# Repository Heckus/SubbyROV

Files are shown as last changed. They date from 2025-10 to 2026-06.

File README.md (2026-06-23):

<div align="center">
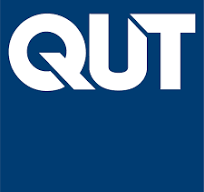
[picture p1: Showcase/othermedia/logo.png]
QUT Logo
  

  
  
  
</div>

# SubbyROV: A Small-Scale Underwater ROV

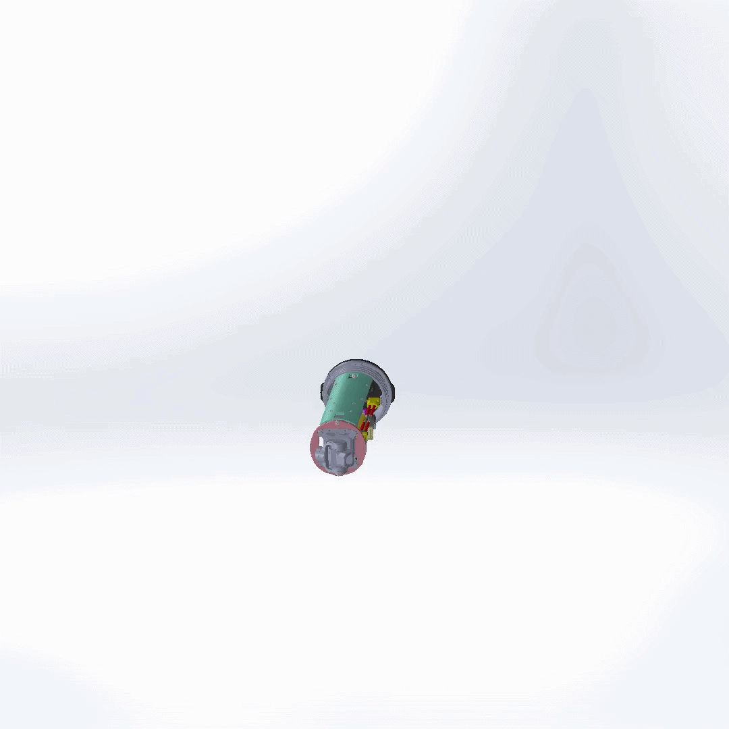
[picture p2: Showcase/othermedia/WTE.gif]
|  |  |
| :---: | :---: |
| *Final SolidWorks Render* | *WTE Design Render* |
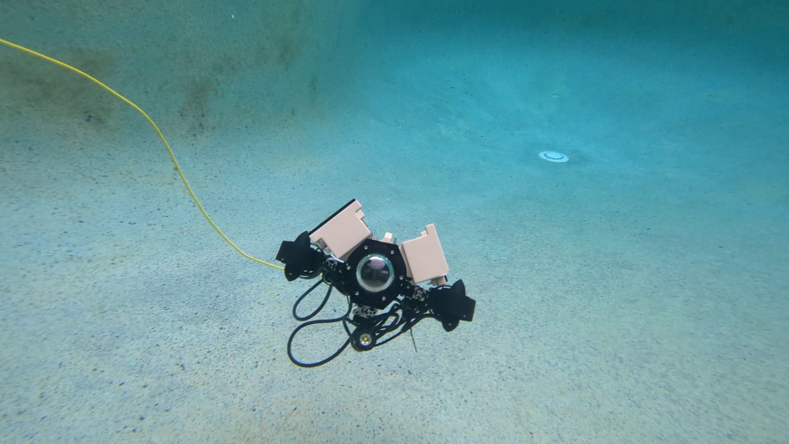
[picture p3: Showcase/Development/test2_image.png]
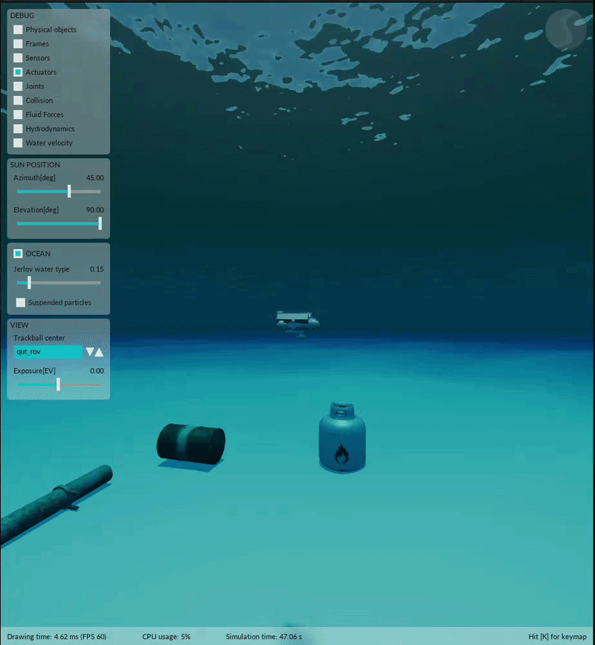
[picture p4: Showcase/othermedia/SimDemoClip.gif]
|  |  |
| *Electronics Tray Prototyping* | *Stonefish Simulation Demo* |

## About the SubbyROV Project

This project, part of the EGH400 and EGH490 Research Projects at Queensland University of Technology (QUT), documents the development of a small-scale, research-grade Remotely Operated Vehicle (ROV).

This repository serves as the open-source hub for the project, containing all design specifications, CAD models, software, and simulation files.

### Motivation

While QUT possesses a capable BlueROV2, its large size, complex handling, and setup requirements (e.g., pool approval) make it impractical for rapid prototyping, small-scale tests, or educational demonstrations.

This project aims to fill that gap by creating a highly modular, cost-effective, and compact ROV. The primary objective is to build a fully operational vehicle that can serve as:

1.  A versatile testbed for novel Machine Learning (ML) control pipelines and advanced LQI controllers.
2.  An accessible and portable platform for QUT open days and demonstrations.

### At a Glance & Bill of Materials (BOM)

The SubbyROV is designed from the ground up to be small, agile, and computationally capable, using a mix of Commercial-Off-The-Shelf (COTS) and custom 3D-printed parts. 

| Specification | Details |
| :--- | :--- |
| **Project Name** | SubbyROV  |
| **Structure** | Blue Robotics 3" watertight enclosure on a custom aluminum Item profile frame. |
| **Propulsion** | 4 x APISQUEEN U2 MINI thrusters with external waterproof ESCs. |
| **Configuration** | Experimental 45-45 degree vectored thruster layout. |
| **Main Controller** | Pixhawk 6X flight controller. |
| **Software** | ArduSub firmware communicating via MAVLink protocol. |
| **Camera** | Z-1 Mini gimballed camera. |
| **Communication** | Fathom-X Tether Interface Boards for Ethernet-over-tether. |
| **Power** | Tattu 5200mAh 4S (14.8V) LiPo Battery. |
| **Est. Runtime** | ~32 minutes (at typical cruising draw). |
| **Total Weight** | ~3.2 kg (3,209.29 g) |
| **Total Cost** | $2,884.38 AUD |

*Note: For the full itemized Bill of Materials, refer to Appendix B of the Final Project Report in the `/Documentation` folder.*

## System Design Architecture

<p align="center">
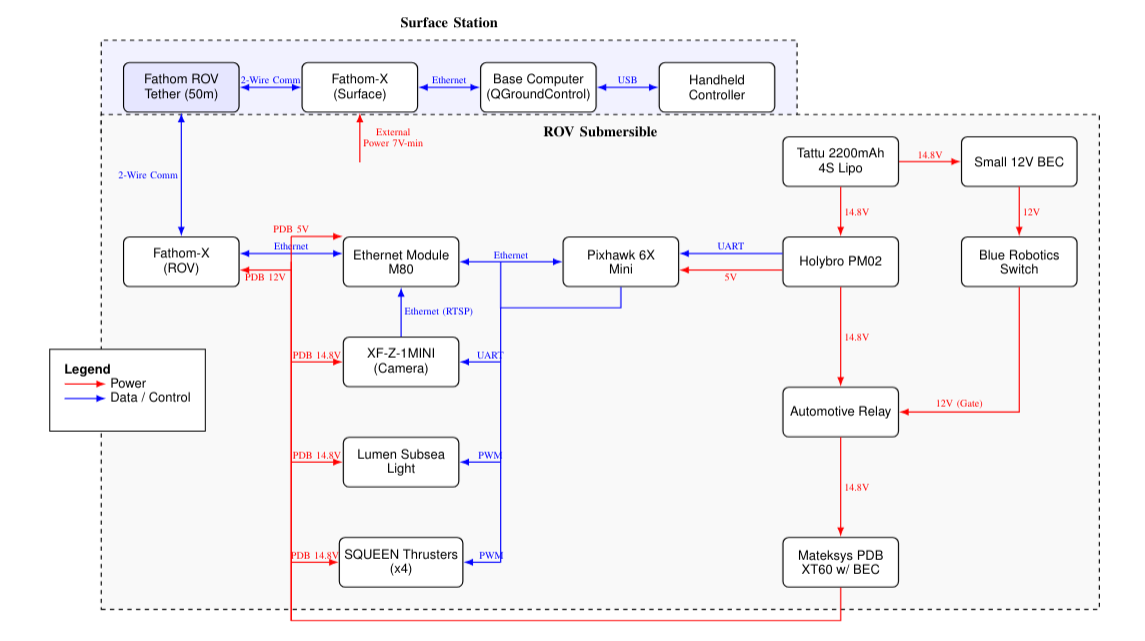
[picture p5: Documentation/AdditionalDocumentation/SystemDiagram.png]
System Diagram
  
</p>

The SubbyROV operates on a robust, decentralized communication and control architecture designed for maximum reliability and modularity. At its core, the **Pixhawk 6X** flight controller runs the ArduSub firmware, which handles low-level stabilization and thruster mixing for the 4-thruster vectored configuration.

Surface communication is achieved through **Fathom-X** Tether Interface Boards, which provide a high-speed Ethernet connection over a single twisted pair tether. This Ethernet link allows a top-side control station running QGroundControl or a custom ROS2 ground station to send MAVLink commands and receive live HD video streams from the internal IP camera, bypassing the need for heavy, multi-wire tethers.

## Project Status

**Current Status:** The primary hardware development and initial manual testing phases have successfully concluded. The SubbyROV has demonstrated watertight integrity, stable camera streaming, and reliable basic teleoperation during pool testing.

**Future Work:** The project is currently being continued by Brad Edwards. Building upon the solid mechanical and electrical foundation, the next major phase focuses heavily on software and control. Utilizing the digital twin developed in Stonefish, Brad is actively working on:
- Implementing advanced underactuated 4-thruster control laws (such as LQI controllers).
- Developing autonomous navigation and pathing capabilities.
- Integrating computer vision algorithms to transition the ROV from a manually operated prototype to a fully capable autonomous testbed.

## Stonefish Simulation Environment

To accelerate the development of complex underactuated control systems and autonomous behaviors without risking the physical hardware, a custom ROS2 package `stonefish_qut_rov` has been developed. 

Leveraging the **Stonefish** marine simulator, this digital twin accurately models the ROV's hydrodynamics and vectored thruster configuration. 

**Key Simulation Capabilities Include:**
- `teleop.py`: Manual teleoperation and thrust testing.
- `station_keeping_node.py`: Advanced depth and heading holding algorithms.
- `pid_controller.py`: Tuning PID control loops for stable navigation.
- `ball_centering.py`: Computer vision testing for autonomous object tracking using the simulated camera feed.

## Repository Contents

* **/CAD:** All SolidWorks 2025 part files, assembly files, and technical drawings for the final design. These have been converted to STEP files for accessability.
* **/StonefishSimulation:** Custom ROS2 package containing the Stonefish digital twin, launch files, and autonomous Python nodes.
* **/Documentation:** The final project reports, complete Bill of Materials (BOM), additional information, and presentations.
* **/Showcase:** Images, GIFs, and media videos showcasing the prototype build, testing and SolidWorks renders.

## The Team

This capstone project is proudly developed by student engineers at QUT, under the supervision of Tobias Fischer.

<table>
  <tr>
    <td align="center">
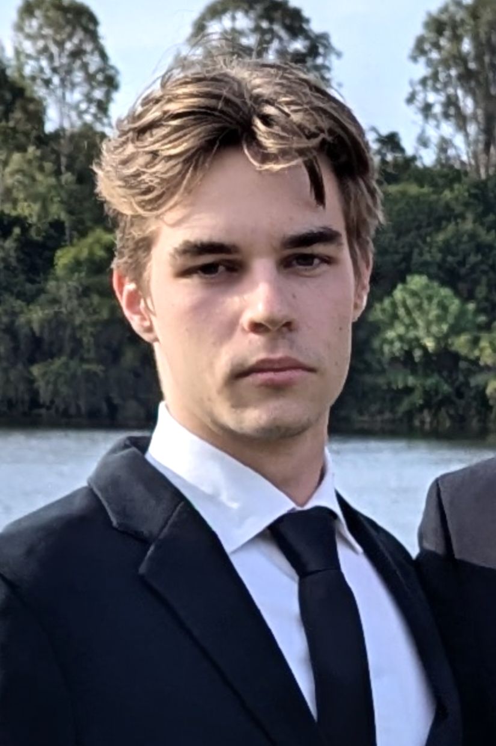
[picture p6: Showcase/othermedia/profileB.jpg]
Joshua Hecke
      
      <br />
      <b>Joshua Hecke</b>
      <br />
      <i>Lead Mechatronics Engineer</i>
    </td>
    <td align="center">
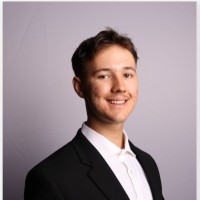
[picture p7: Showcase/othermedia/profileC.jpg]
Brad Edwards
      
      <br />
      <b>Brad Edwards</b>
      <br />
      <i>Simulation & Control Engineer</i>
    </td>
    <td align="center">
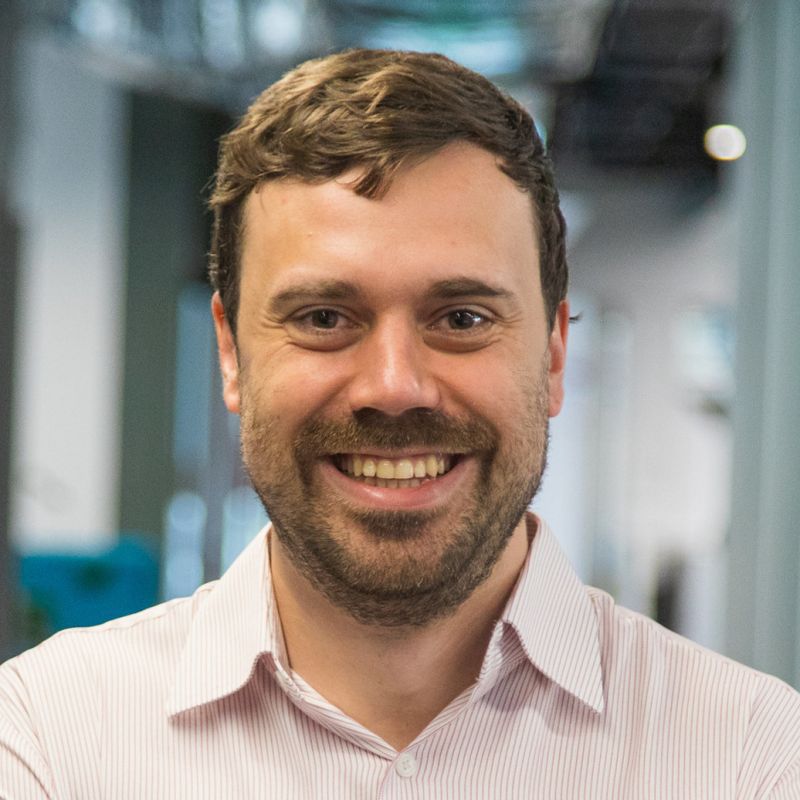
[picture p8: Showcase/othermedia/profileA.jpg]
Tobias Fischer
      
      <br />
      <b>Tobias Fischer</b>
      <br />
      <i>Project Lead & Supervisor</i>
    </td>
  </tr>
</table>

**Supervisor GitHub:** [tobias-fischer](https://github.com/tobias-fischer)

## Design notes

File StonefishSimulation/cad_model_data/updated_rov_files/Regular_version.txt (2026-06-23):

Mass properties of Assembly
     Configuration: VolumeBouyancy
     Coordinate system: -- default --

Mass = 4015.03 grams

Volume = 4741897.54 cubic millimeters

Surface area = 1208562.63  square millimeters

Center of mass: ( millimeters )
	X = -0.77
	Y = -0.01
	Z = 0.02

Principal axes of inertia and principal moments of inertia: ( grams *  square millimeters )
Taken at the center of mass.
	 Ix = (-0.09,  1.00, -0.01)   	Px = 27051658.27
	 Iy = (-1.00, -0.09, -0.03)   	Py = 28815199.11
	 Iz = (-0.04,  0.01,  1.00)   	Pz = 44474214.11

Moments of inertia: ( grams *  square millimeters )
Taken at the center of mass and aligned with the output coordinate system. (Using positive tensor notation.)
	Lxx = 28820371.93	Lxy = -156480.34	Lxz = 562778.95
	Lyx = -156480.34	Lyy = 27068167.83	Lyz = -164466.08
	Lzx = 562778.95	Lzy = -164466.08	Lzz = 44452531.73

Moments of inertia: ( grams *  square millimeters )
Taken at the output coordinate system. (Using positive tensor notation.)
	Ixx = 28820373.84	Ixy = -156438.81	Ixz = 562725.78
	Iyx = -156438.81	Iyy = 27070553.35	Iyz = -164467.00
	Izx = 562725.78	Izy = -164467.00	Izz = 44454916.79

One or more components have overridden mass properties:
	WTE3-P-RETAINING-RING-R1<1><Default>@Hull_v5<1><Default>
	flange3-BR-100416_RevC.step<1><Default>@Hull_v5<1><Default>
	BR-102678-003_RevC.step<1><Default>@Hull_v5<1><Default>
	BR-102678-003_RevC.step<2><Default>@Hull_v5<1><Default>
	BR-102678-003_RevC.step<3><Default>@Hull_v5<1><Default>
	BR-102678-003_RevC.step<4><Default>@Hull_v5<1><Default>
	ItemBar-150mm<1><Default>@Hull_v5<1><Default>
	SideItemMount<1><Default>@Hull_v5<1><Default>
	SideItemMount<2><Default>@Hull_v5<1><Default>
	SideItemMount<3><Default>@Hull_v5<1><Default>
	SideItemMount<4><Default>@Hull_v5<1><Default>
	ItemBar-150mm<2><Default>@Hull_v5<1><Default>
	ItemBar-150mm<3><Default>@Hull_v5<1><Default>
	ItemBar-150mm<4><Default>@Hull_v5<1><Default>
	LUMEN-ASM-R3-PUBLIC.STEP@Hull_v5
	U2-Thruster@Hull_v5
	U2-Thruster@Hull_v5
	U2-Thruster@Hull_v5
	U2-Thruster@Hull_v5
	BuoyancyHandle<2><Default>@Hull_v5<1><Default>
	LightMount<1><Default>@Hull_v5<1><Default>
	ThrusterMount90<1><Default>@Hull_v5<1><Default>
	ThrusterMount180<1><Default>@Hull_v5<1><Default>
	ThrusterMount90<2><Default>@Hull_v5<1><Default>
	ThrusterMount180<2><Default>@Hull_v5<1><Default>
	flange3-BR-100416_RevC.step<1><Default>@Wte_v5<1><Default>
	WTE3-M-END-CAP-7-HOLE-R1<1><Default>@Wte_v5<1><Default>
	SWITCH-M10-5A-R1-RP.STEP@Wte_v5
	WLP-M10-7.5MM-PUBLIC<1><Default>@Wte_v5<1><Default>
	WLP-M10-7.5MM-PUBLIC<2><Default>@Wte_v5<1><Default>
	WLP-M10-7.5MM-PUBLIC<3><Default>@Wte_v5<1><Default>
	WLP-M10-7.5MM-PUBLIC<4><Default>@Wte_v5<1><Default>
	WLP-M10-7.5MM-PUBLIC<5><Default>@Wte_v5<1><Default>
	WLP-M10-7.5MM-PUBLIC<6><Default>@Wte_v5<1><Default>
	Pixhawk6xMini@Wte_v5
	FATHOM-X-ASM-R1<1><Default>@Wte_v5<1><Default>
	PDB-XT60-Model<1><Default>@Wte_v5<1><Default>
	Circle-BR-103131-300_RevB<2><Default>@Wte_v5<1><Default>
	Willow Durakool DG82 Series Automotive Relays<1><Default>@Wte_v5<1><Default>
	Camera_assembly@Wte_v5
	InternalMount<1><Default>@Wte_v5<1><Default>
	TATTU 2200mAh 14.8V 45C 4S1P Lipo Battery Pack with XT60 Plug<1><Default>@Wte_v5<1><Default>
	eth-38658-2.1@Wte_v5
	PowerMount2<1><Default>@Wte_v5<1><Default>
	PowerMount3<1><Default>@Wte_v5<1><Default>
	TubeHollowSpace<1><Default>

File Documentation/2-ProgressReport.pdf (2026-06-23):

## EGH400-1 Progress Report

# Development of a Small-Scale Underwater Remotely

# Operated Vehicle (ROV)

Faculty of Engineering

October 23, 2025

Unit Code: | EGH400 - Research Project 1
Assessment: | #2 - Progress Report
Supervisor: | Tobias Fischer
Student Engineer: | Joshua Hecke
Student ID: | n11585382

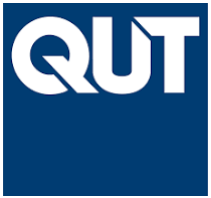
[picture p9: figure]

This report is submitted in partial fulfilment of the requirements for EGH400.

## Contents

1 | Introduction | 1
2 Literature Review | 1
3 Project Progress and Achievements | 3
4 Project Management | 11
5 Ethical Considerations | 12
6 Resources and Stakeholder Engagement | 15
7 Conclusion | 16
8 Future Work | 16
A Project Timeline | 20
B Technical Drawings | 22
C BOM (Full) | 24

D Full Risk Assessment | 26
E Original Literature Review (from Project Proposal) | 33

ii

## Acronyms

AUV Autonomous Underwater Vehicle. 1, 34, 35

CAD Computer-Aided Design. 1, 35

CFD Computational Fluid Dynamics. 35

DOF Degrees of Freedom. 1, 2, 33, 35

GUI Graphical User Interface. 1

IMU Inertial Measurement Unit. 34

ML Machine Learning. 1, 2

PID Proportional-Integral-Derivative. 2, 35

QUT Queensland University of Technology. 1

ROS Robot Operating System. 2, 34

ROV Remotely Operated Vehicle. 1–3, 15, 16, 33–35

iii

## 1 Introduction

This project aims to design, develop, and validate a small-scale underwater Remotely Operated Vehicle (ROV) to address the gap in accessible research-grade platforms. The primary objective is to create a fully operational vehicle for use in Queensland University of Technology (QUT) demonstrations and as a versatile testbed for novel Machine Learning (ML) control pipelines. The research focuses on integrating robust

hardware and software solutions within a compact form factor, a challenge not fully addressed by larger commercial systems.
The expected outcomes of this project include a fully assembled ROV, complete Computer-Aided Design (CAD) drawings, control system software with a basic Graphical User Interface (GUI), and a final report

detailing the design, methodology, and performance results. This will be done in three phases:

- Phase 1: Research and Design (current phase)
- Phase 2: Validation and Prototyping
- Phase 3: Testing, Evaluation and Reporting

## 2 Literature Review

### 2.1 Literature Review Summary

A comprehensive survey of existing literature reveals a distinct gap in the field of underwater robotics for small-scale, low-cost, and modular Remotely Operated Vehicles (ROVs) that are also computationally

equipped for modern research. While the domain is populated with large, work-class vehicles for industrial applications and highly specialised Autonomous Underwater Vehicles (Autonomous Underwater Vehicle (AUV)s), these platforms are often financially and logistically prohibitive for academic research and rapid prototyping [25]. This review synthesised key design philosophies and technical trade-offs from a range

of academic papers and technical reports, establishing a theoretical foundation to inform the design of a novel research platform.
A primary theme is the fundamental decision in chassis architecture, which presents a trade-off between modularity and hydrodynamic performance. Open-frame designs are consistently favoured for research and educational platforms due to their inherent modularity, which simplifies the process of mounting, testing, and reconfiguring sensors, thrusters, and other payloads, as seen in vehicles like the eROV [5].

This adaptability is paramount for a vehicle intended to serve as a testbed. Conversely, enclosed, torpedo-style hulls are chosen when operational efficiency, speed, and endurance are the primary drivers, as their streamlined form minimises drag [13, 29]. For this project’s objectives, the principles of the open-frame

design are more closely aligned with the need for a flexible and extensible research platform. Maneuverability in a compact form factor is another critical consideration, heavily influenced by thruster configuration. While simple 3-thruster systems can provide basic motion [27], the literature indicates that full 6-Degrees of Freedom (DOF) control is a key enabler for complex inspection and intervention tasks. This is typically achieved with six or more thrusters [15, 17]. A common and effective strategy is the use

of a vectored thruster arrangement, where horizontal thrusters are angled to provide coupled control of surge, sway, and yaw [11, 25]. This approach allows for high agility and omnidirectional movement without

a large physical footprint, a key idea that heavily influenced this project’s propulsion system design.
The selection of onboard hardware reflects a clear scalability based on mission complexity and budget. At the lower end, simple microcontrollers like Arduino are sufficient for basic teleoperation and sensor reading [1, 27]. However, to serve as a viable testbed for modern algorithms, particularly in computer vision

and ML, a more powerful single-board computer, such as a Raspberry Pi or Nvidia Jetson, is essential. These platforms provide the necessary processing power for real-time video streaming, network communication, and running inference models [11, 12, 16, 28]. This distinction highlights the necessity of selecting a com-

panion computer that not only meets current needs but also provides headroom for future computational expansion.
Finally, the software architecture and control system design are integral to the vehicle’s capability. The Robot Operating System (Robot Operating System (ROS)) is frequently cited as the framework of choice for

complex, modular robotic systems due to its robust inter-process communication, extensive libraries, and available hardware drivers [15, 16]. While simpler platforms may use custom firmware, open-source solu-

tions like ArduSub offer a powerful, community-supported alternative that can significantly accelerate development [10]. At the control level, the Proportional-Integral-Derivative (Proportional-Integral-Derivative (PID)) controller is a foundational and ubiquitous method for achieving basic stability, such as depth and heading hold [12,17]. However, its performance can degrade in the presence of external disturbances, lead-

ing more advanced projects to explore robust control techniques like Sliding Mode Control or Fuzzy Logic controllers [9, 27]. These established ideas from the literature provide a clear benchmark against which

this project’s design choices and practical progress can be evaluated. The full literature review is available in Appendix B for further detail.

### 2.2 Evaluation of Literature Review Findings and New Literature

During the phase one of the project it was found that the insights from the literature review were largely applicable to the design and development of the medium scale ROV but not small scale ROVs. Using 6 thrusters to achieve 6 DOF was found to be impractical for a small scale ROV due to size and power consumption constraints. This was also true for the use of a companion computer such as a raspberry pi or nvidia jetson. These components while useful for ML applications, were found to be too large and power hungry for the size of ROV being designed. This lead to further literature review to find alternatives that would suit the size and power constraints of the small scale ROV. A paper by Sujan et al. (2024) [22]

presented a design for a small scale ROV that used 4 thrusters in a vectored configuration to achieve underactuated control of the ROV as seen in figure 1. This design was found to be more suitable for the project as it allowed for a smaller footprint and lower power consumption, however the underactuation resulted in the lack of pitch control.

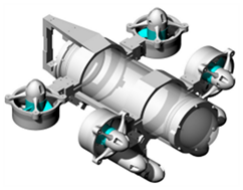
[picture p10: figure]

Figure 1: 4 thruster vectored configuration for small scale ROV from Sujan et al. (2024) [22].

This approach was modified into a experimental design using custom 45-45 degree brackets to give each thruster a vectored force. This design will need to be tested to see if it can achieve the desired dof and control. The benefit of this design is that it reduces the number of thrusters from 6 to 4, which reduces the size of the battery and ESC’s required. This is a key area for the small scale ROV as it allows for a smaller hull and overall size, as well as cost reductions.
Due to sizing constraints found during initial design phase it was found that lithium-ion batteries were too large and had to be replaced with the smaller, lithium-ion polymer battery. While Lithium-ion Polymer (LiPo) batteries were selected for this project due to their high energy density and discharge rates essential

for powering the thrusters, their use introduces significant safety considerations. An issues paper by the Australian Competition & Consumer Commission (ACCC) highlights the primary hazard associated with Li-ion batteries as ’thermal runaway’ a rapid, self-sustaining temperature increase [4]. This event can be triggered by manufacturing defects, over-charging, physical impact (a key risk during ROV operations), or

water ingress leading to a short circuit. The consequences of thermal runaway are severe, including intense fires that are difficult to extinguish, potential explosions, and the release of toxic and flammable gases [4]. For this project, these risks underscore the criticality of a robust, impact-resistant, and completely

watertight enclosure for the battery, as well as strict adherence to balanced charging protocols. A detailed Risk Assessment has been conducted (see Section 4.1) to identify and mitigate these hazards, ensuring the

safe operation of the ROV in aquatic environments.
Finally, new literature on the mavlink communication protocol was found as the small size rov was not large enough to hold a companion computer. This lead to the use of a pixhawk flight controller as the main computer, which uses the mavlink protocol to communicate with the surface station. Mavlink is a lightweight, header-only message marshalling library for micro air vehicles. It is designed as a very efficient communication protocol between drones and/or ground control stations [18]. This protocol is widely used

in the drone community and has been adapted for use in underwater vehicles. The use of mavlink allows for a reliable and efficient communication link between the rov and the surface station, which is essential for remote operation and data transfer.

## 3 Project Progress and Achievements

This section details the progress made in the project to date, highlighting key achievements and milestones. These include design work, component procurement, assembly, experimentation, and any technical drawings produced. Below is a summary of the major milestones achieved so far:

- Design iteration and problem-solving to meet research objectives
- Bom produced and components sourced.
- Final Solution in SolidWorks 2023 produced
- Construction of prototypes started
- Risk assessment completed and submitted for review
- Required hardware sourced and prepared for simulation

These items while not fully completing the first research and design phase (not complete as components are still missing), place the project in a good position to move into phase 2.

### 3.1 Design Iterations

When starting the design phase, components were picked based of literature review and existing designs. Key components that fall under this were the thrusters, hull, battery, main computer and camera. The initial design also followed this with 6 thrusters in a vectored configuration to allow for 6 degrees of freedom. Below is a rendering of the first design iterations Hull and WTE designs.

### 3.1.1 Mechanical Design

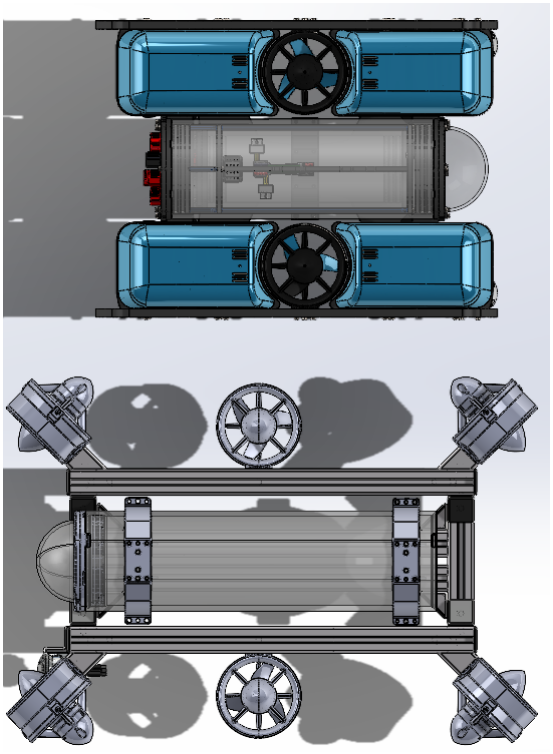
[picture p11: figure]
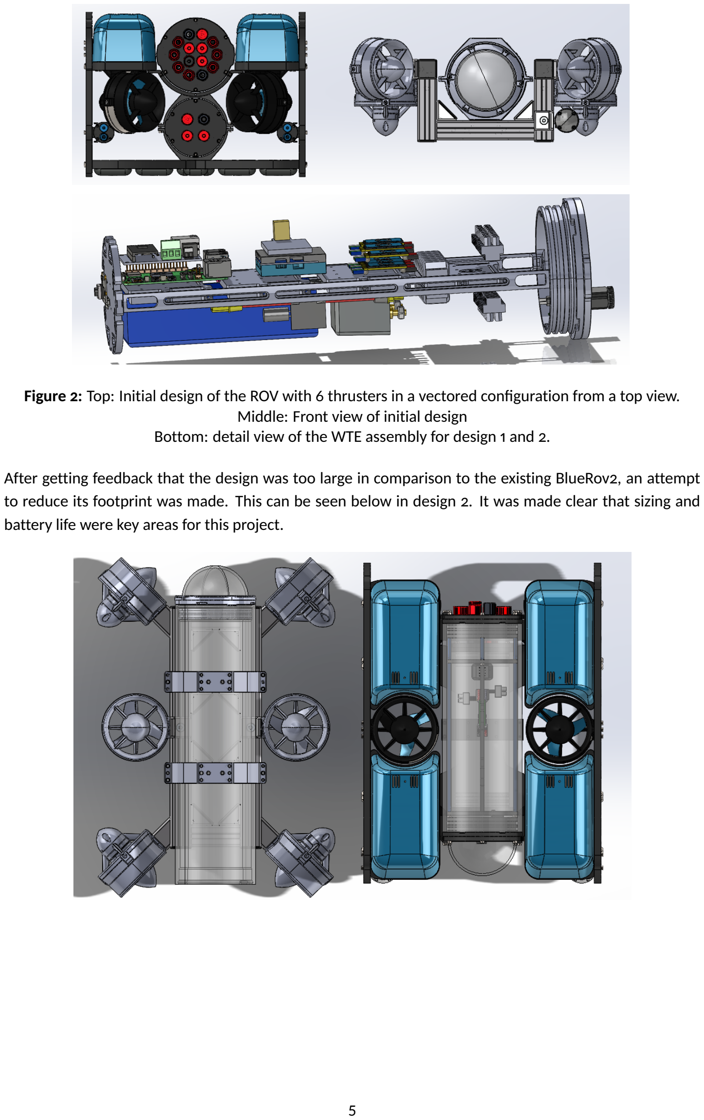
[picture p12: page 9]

Figure 2: Top: Initial design of the ROV with 6 thrusters in a vectored configuration from a top view. Middle: Front view of initial design Bottom: detail view of the WTE assembly for design 1 and 2.

After getting feedback that the design was too large in comparison to the existing BlueRov2, an attempt to reduce its footprint was made. This can be seen below in design 2. It was made clear that sizing and battery life were key areas for this project.

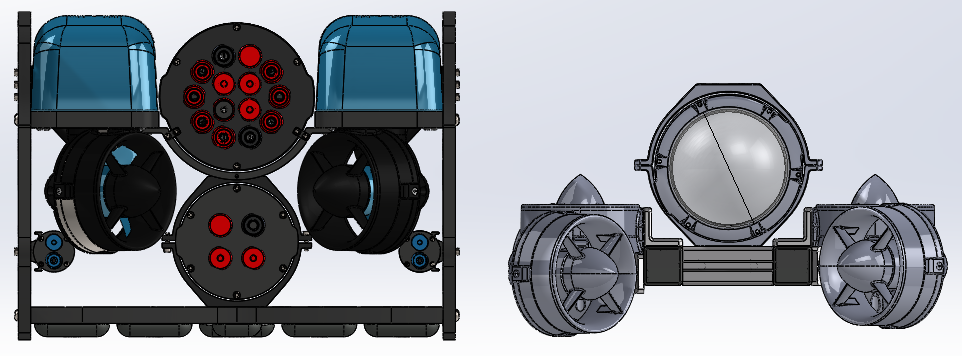
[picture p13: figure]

Figure 3: Top: overall second design of the ROV with 6 thrusters in a smaller footprint in comparison to the BlueRov2 from top view. Bottom: size comparison of design 2 to blue robotics blue rov2 front view.

as seen in figure 3, the second design was still too bulky and had a large footprint relative to the existing BlueRov2. This was due to the large battery required for the selected T200 thrusters, the 6 ESC’s required for thrusters and the inclusion of the companion computer the pi 5 in the chassis. This lead to a meeting with the supervisor to address the limitation of size with these components. The outcomes of the meeting where

- Reduce the number of thrusters to reduce size of battery and ESC’s
- research different thrusters to get a smaller footprint
- Move the companion computer outside of the main hull to reduce size
- Connect the autopilot to the companion computer via a short tether These changes lead to a new design which had its own set of challenges. these included sourcing new thrusters, a change in camera as the original Pi compatible camera could not interface with the autopilot. Another challenge was maintaining a high dof with only 4 thrusters. A experimental design using a custom 45-45 degree bracket was made to give each thruster a vectored force. A custom control system will need to be implemented, however if successful the power consumption will be lower and the size of the ROV will be smaller. The benefit of removing the companion computer from the main hull allows the hull to have a smaller diameter and shorter in length. This change is what got design 3 to be accepted and allowed for prototyping to start. Below is design 3 that will be prototyped.

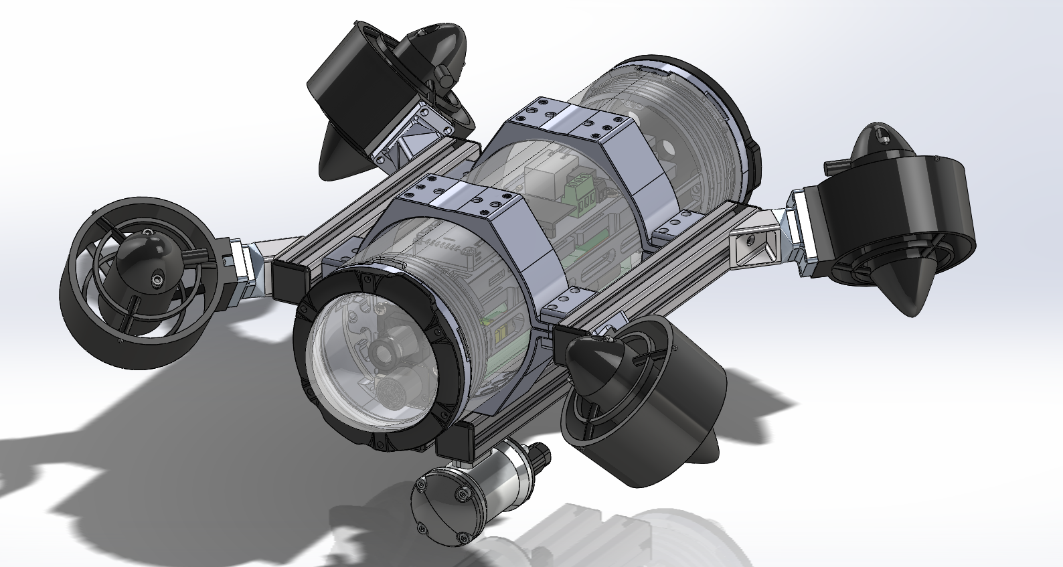
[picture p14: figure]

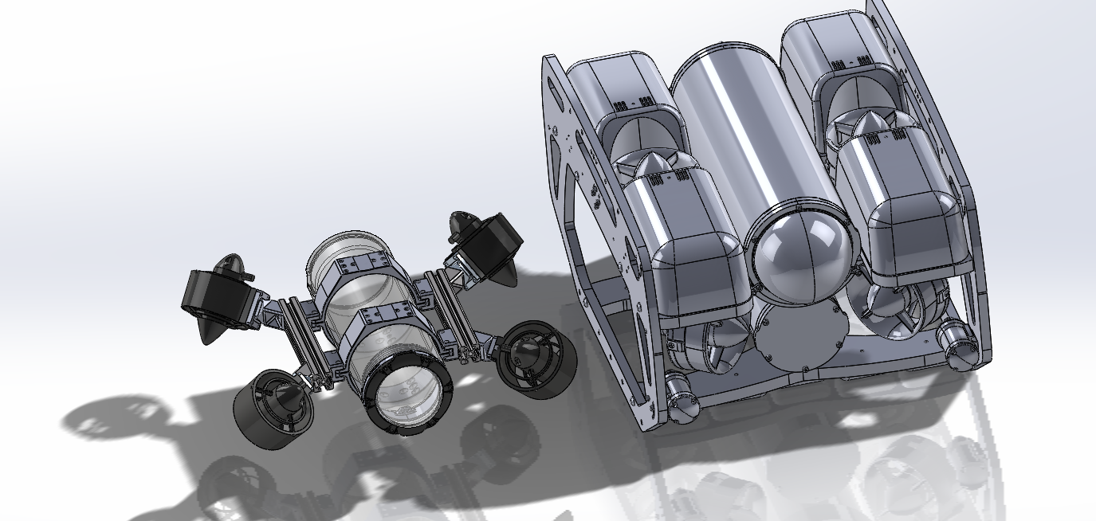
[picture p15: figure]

Figure 4: Top: overall third design of the ROV with 4 thrusters in a smaller footprint.
Bottom: size comparison of design 3 to blue robotics blue rov2.

This design used 4x U2 Mini thrusters by apisqueen to reduce size and power consumption. The battery was changed to a 4s 5200mah lipo battery to power the thrusters and electronics.

After it was accepted it was revealed that the camera selected was no longer on the market. This lead to a final design iteration to change the camera to a z-1 mini gimballed camera and the addition of a handle for safer handling. This required a new mount to be designed to fit inside the blue robotics 3” diameter watertight enclosure. This final design can be seen below in figure 6. However there was still some uncertainty with this design. Key areas of uncertainty are

– The 3D printed brackets for the thrusters need to be tested for strength

– The waterproofing of the main hull and WTE’s need to be tested

– Will the custom 45 degree brackets work as intended

– Design validation needs to be done to calculate the buoyancy and additional volume required

to achieve neutral buoyancy

these are planned to be addressed in the next phase of the project.

### 3.1.2 Electronics and System Integration

The electronics system is designed for reliability and performance, centred around a Pixhawk 6X flight controller and Z-1 Mini gimballed camera. Communication with the surface is achieved via a pair of Fathom-X Tether Interface Boards, which enable a robust, high-bandwidth Ethernet-overpower connection to a ground station. A lumen Subsea light will act as a inital payload but this can be swapped out for other sensors in the future. A Matek Systems PDB XT60 is used to simplify wiring and power distribution to the four APISQUEEN U2 MINI thrusters, each with there own external ECS and capable of delivering up to 130W of thrust. The entire system is powered by a small onboard LiPo battery, chosen for its high discharge rate and energy density, ensuring sufficient power for extended operation. The electronics are housed within a Blue Robotics 3" diameter watertight enclosure, providing protection against water ingress while allowing easy access for maintenance and upgrades.

### 3.1.3 Power Budget and Runtime Analysis

A detailed power budget was created to inform battery selection and estimate operational endurance. The power consumption of major components was determined from manufacturer datasheets, as summarised below:

– APISQUEEN U2 MINI Thrusters (x4): The most significant power consumers, drawing up to

130W each at maximum throttle. A typical cruising state is estimated at 25-30% throttle, corresponding to approximately 35W per thruster.

– Pixhawk 6X Mini: A consistent draw of approximately 3.0W.

– Fathom-X Boards & Camera: A combined constant draw of around 1.0W.

Based on this, the total system power draw for different operational scenarios was calculated:

– Idle: 8W

– Cruising: 144W

– Maximum Thrust: 524W

The chosen power source is a Tattu 5200mAh 4S (14.8V) LiPo battery, which has a nominal energy capacity of 5.2 Ah × 14.8 V = 76.96 Wh. Using this, the vehicle’s runtime can be estimated:

Runtime (Cruising) =

76.96 Wh
144 W

≈ 0.53 hours ≈ 32 minutes

This runtime is deemed sufficient for the demonstration and testing objectives of the project.

### 3.2 Bill of Materials (BOM)

Significant progress has been made in sourcing and ordering components. All critical long-lead items, including the flight controller, thrusters, and enclosure are currently received. Mounting hardware is on order and the power sensor is on reorder due to a mistake with shipping. A full BOM can be found in the appendix. The total estimated cost for all components is currently $2900.

### 3.3 Final Design of Phase 1 in SolidWorks

The final design from phase 1 of the ROV has been completed in SolidWorks, incorporating all necessary modifications and optimizations identified during the design review process. The assembly includes detailed models of all major components, including the thrusters, mounting hardware and electronics enclosure. It is missing buoyancy elements as these will be designed in phase 2. Below are the renderings of the final design, technical drawing with dimensions included can be found in the appendix.

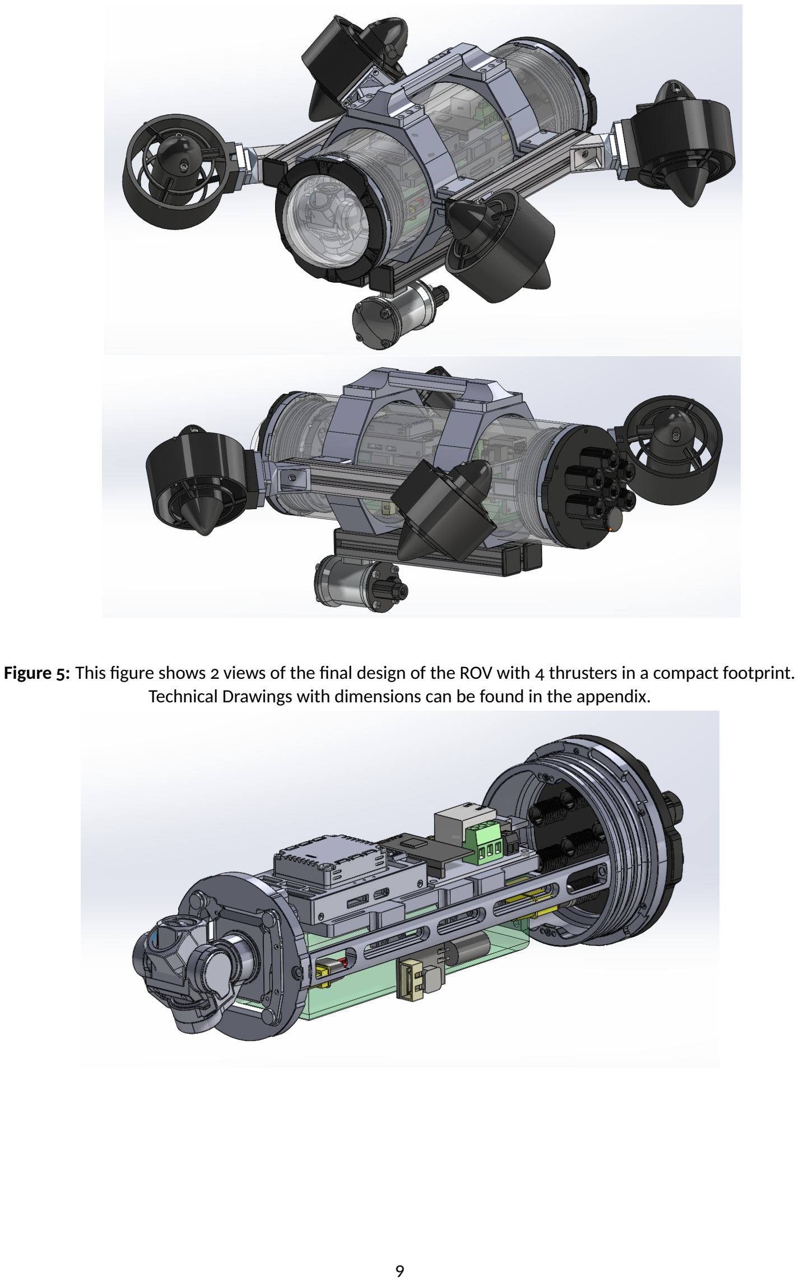
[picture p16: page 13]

Figure 5: This figure shows 2 views of the final design of the ROV with 4 thrusters in a compact footprint. Technical Drawings with dimensions can be found in the appendix.

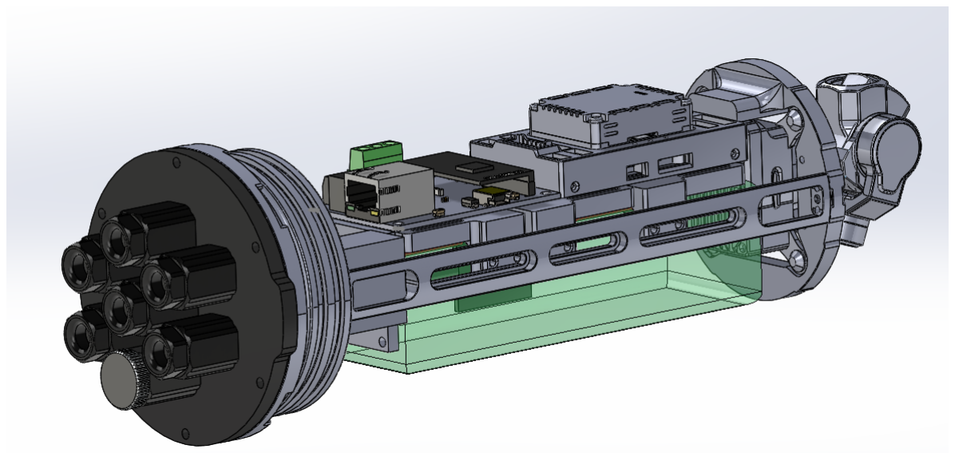
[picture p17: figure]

Figure 6: Final design from phase 1 of the the water tight enclosure with the blue robotics 3" diameter product. This includes the new camera mount and handle added from design 3. Technical Drawings with dimensions can be found in the appendix.

### 3.4 Prototyping and Assembly Testing

To validate the Solidworks design, inital construction of the WTE has started. This includeds the mounting of the interal control and power electronics. It was found through this prototype that some of the mounting holes needed slight modification. However once this was done the Pixhawk 6X, PDB-XT60 and Fathom-X boards fit well inside the enclosure. Below are some photos of the assembly process.

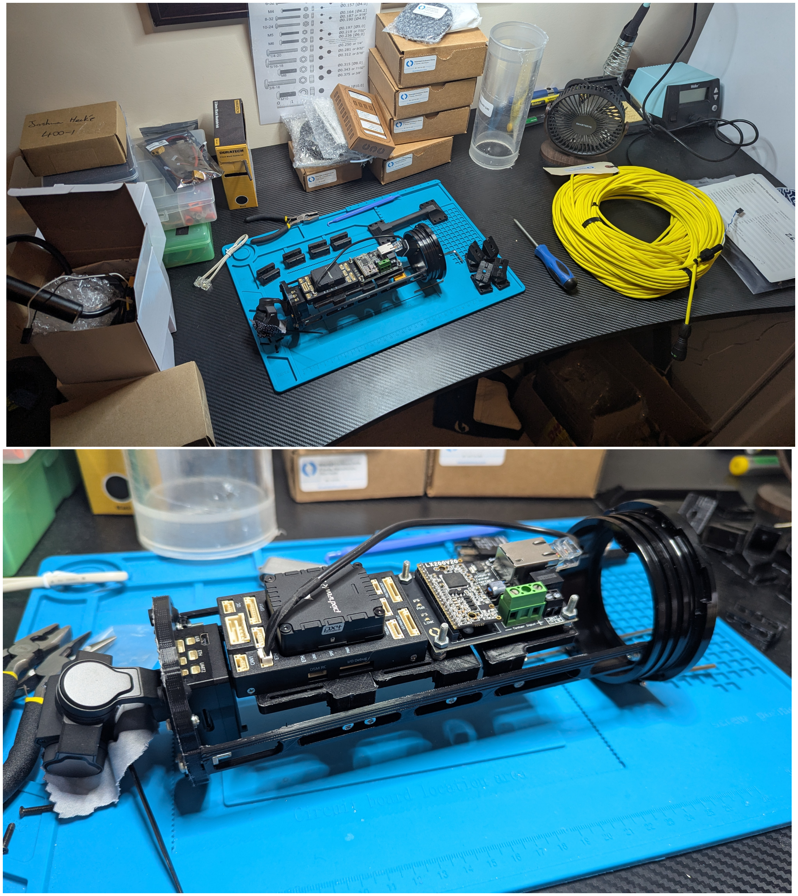
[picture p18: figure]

Figure 7: Top: Photo of home workshop with the 3d printed parts and initial assembly of the watertight enclosure.
Bottom: Close up of the internal electronics showing the Pixhawk 6X, PDB-XT60 and Fathom-X boards.

### 3.5 Hardware and preparation for Simulation

Currently no experimentation or testing has been done as the project is still in the design phase. Once the design is completed the project will move into phase 2, this will start in Solidworks where mass/inertial properties will be calculated for each component. The design will then be exported into a urdf file and imported into ros2/gazebo with a buoyancy plugin to validate the design. A ubuntu environment has be setup ready for this step. The method involves calculating the force required to achieve neutral buoyancy and adding enough volume to produce a buoyancy force equal to the offset force. Once the design is validated, a prototype will be built and tested in a pool environment after waterproof tests are done.

## 4 Project Management

### 4.1 Risk Assessment

A comprehensive risk assessment (RA), titled "Design of small scale Remotely Operated Vehicle -Underwater Robot" (ID: 18339), was submitted through the QUT HSE Hub to ensure the safety of all

personnel and equipment. This document identifies the primary hazards associated with the project and, more importantly, establishes the formal control measures that will be implemented to mitigate them. The full RA document is attached in Appendix D.

The key risks and their corresponding mitigation strategies are summarised below:

– Electrical Hazards (LiPo Battery): The primary electrical risk involves the use, handling, storage, and charging of the 5200mAh 4S Lithium-Polymer (LiPo) battery. These batteries have a very

high energy density and discharge rate, requiring strict protocols. The ROV’s internal system is classified as "ultra low voltage" to comply with Australian standards.

Storage: All batteries will be stored in designated fire-resistant LiPo bags or a battery cabinet,

following consultation with S9 technical staff.

Charging: Charging will only be performed in a designated, clear area using a purpose-built

LiPo balance charger. Batteries will be monitored throughout the charging process and never left unattended.

Handling: Only trained, designated operators may handle or connect the battery. A physical inspection for damage, swelling ("puffing"), or low voltage will be conducted before every

use.

Transport: Batteries will be transported in a safe, discharged state within fire-resistant bags.

– Operational Hazards (Electronics and Water): This risk category covers the hazards of operat-

ing a high-power electronic device in and around water, including the specific hazard of water leakage into the main electronics enclosure.

Leak Prevention: A pre-operation checklist will be followed, requiring a visual and physical in-

spection of all O-ring seals, cable penetrators, and enclosure surfaces before every waterbased test.

Leak Detection: During initial submersion in the test tank, the ROV will be closely monitored

for any signs of water ingress.

Electrical Safety: The topside control station and power supply will be plugged into a Ground Fault Circuit Interrupter (GFCI) or Residual Current Device (RCD) protected outlet at all

times.

Facility Safety: Use of any testing facility (e.g., QUT pool, test tanks) will be done only after

receiving formal approval from the appropriate facility manager or body.

– Personnel and Training: The experimental nature of the ROV presents a risk if operated by

untrained personnel.

Designated Operators: Operation is strictly limited to the designated and trained team members (Joshua Hecke, Tobias Fischer, and Scarlett Raine).

Induction Protocol: Any other person must first receive a formal induction and practical train-

ing from a designated operator before they are permitted to operate the vehicle under supervision.

– Chemical Hazards (Waterproofing Sealant): The RA identifies potential hazards related to the

use and storage of Dichtol waterproofing chemicals, which may be required to seal porous 3D-printed components.

Storage: Should these chemicals be required, they will be purchased through S9 and stored in

a designated, ventilated chemical storage cabinet as advised by technical staff.

Handling: Application will be performed in a well-ventilated area (e.g., a fume hood) using the appropriate Personal Protective Equipment (PPE), including gloves and safety glasses.

SDS: The Safety Data Sheet (SDS) for the chemical will be kept on-file and accessible in the lab.

Note on Waterproofing Chemicals: It should be noted that the Dichtol waterproofing chemical,

while included in the RA for completeness, is not currently in use. This chemical was identified for potential future application if the 3D-printed components demonstrate water ingress or degradation after prolonged testing. Its use will be subject to the controls outlined above if and when it is required.

These measures are pending final review for endorsement, with procedures for chemical and battery storage being finalised with S9 staff.

## 5 Ethical Considerations

### 5.1 Code of Ethics

This project is conducted in accordance with the Engineers Australia Code of Ethics [8]. The applica-

tion of these guiding principles throughout the project’s progress is detailed below.

### 5.1.1 Demonstrate Integrity

Integrity has been a foundational principle in all project activities, ensuring honest and respectful conduct.

– Honesty and Trustworthiness (1.2): All project plans, design challenges, and progress have

been communicated with transparency to supervisors and stakeholders. This commitment to openness ensures all involved parties remain fully informed of the project’s status and direc-

tion.

– Respect for Persons (1.3): Input has been actively sought and respectfully considered from

all stakeholders, including academic supervisors, technical staff, and peers. Every contribution is valued, regardless of an individual’s specific technical background, fostering a collaborative

project environment.

### 5.1.2 Practise Competently

The project has been undertaken with a commitment to technical competence and continuous professional development.

– Maintenance of Skills (2.1): To meet the specific design requirements of the ROV chassis, a

proactive effort was made to expand personal capabilities by learning and utilising SolidWorks 2023 for the mechanical design, despite prior experience favouring other CAD platforms.

– Acting on Knowledge (2.2): All significant technical decisions, from component selection to

control system architecture, have been evidence-based. These decisions are underpinned by a thorough review of relevant literature and direct consultation with knowledgeable stakeholders and subject matter experts.

### 5.1.3 Exercise Leadership

Leadership has been demonstrated through proactive, clear, and honest communication with all project participants.

– Effective Communication (3.3): Professional and effective communication has been maintained

with a diverse group of stakeholders, including researchers and laboratory technicians. Through clear emails and meetings, critical information and expert advice have been solicited honestly and efficiently, acknowledging the reliance of the project on their expertise.

### 5.1.4 Promote Sustainability

The design and documentation process has been mindful of the project’s long-term impact and fu-

ture use.

– Balancing Present and Future Needs (4.3): To ensure the project’s longevity, components have

been selected with consideration for their long-term availability, mitigating risks of future obsolescence. Furthermore, a strong emphasis has been placed on thorough documentation, ensuring that the project’s outcomes and learnings are accessible and can be effectively utilised by future students and researchers.

### 5.2 Sustainability Considerations

The development of the SubbyROV platform has incorporated sustainability considerations throughout the design and component selection process. The project’s sustainability is assessed across three key pillars: environmental, economic, and social, ensuring a responsible approach to engineering that extends beyond the project’s immediate technical goals.

### 5.2.1 Environmental Sustainability

Environmental sustainability has been a primary driver in the selection of materials and the operational design of the ROV.

– Material Selection: The ROV’s chassis is constructed from anodised aluminium Item profile. Aluminium is not only durable and corrosion-resistant, extending the vehicle’s operational lifespan, but it is also highly recyclable. The primary enclosure and thruster bodies are made from robust polymers designed for longevity in harsh marine environments, minimising the need for replacements and reducing potential waste.

– Energy Efficiency: The power system was designed for maximum efficiency to prolong opera-

tional time and reduce the frequency of battery charging cycles. As detailed in the power budget analysis, components such as the Pixhawk flight controller and the APISQUEEN U2 MINI thrusters were selected for their favourable power-to-performance ratio.

– Minimal Operational Impact: As an electrically powered vehicle, the ROV produces no direct

emissions. Its small size and low-noise thrusters are intended to minimise disturbance to marine life during research and demonstration activities.

### 5.2.2 Economic Sustainability

The long-term economic viability of the platform is ensured through a modular and repairable design philosophy.

– Modularity and Reusability: The use of a standardised Item Profile frame is a cornerstone of the design’s economic sustainability. This modularity allows for the simple addition, removal, or repositioning of components, such as sensors, manipulators, or buoyancy blocks. This means the ROV is not a static design but an adaptable platform that can be reconfigured for future projects and research questions without requiring a complete rebuild, thus maximising the return on the initial investment.

– Repairability and Maintenance: The reliance on Commercial-Off-The-Shelf (COTS) components

from reputable suppliers like Blue Robotics and HolyBro, as listed in the Bill of Materials, simplifies maintenance and repairs. Standardised parts are readily available, reducing downtime and lowering long-term maintenance costs compared to a system built with fully custom, oneoff components. This is further backed the use of 3D printed parts for mounting components, allowing for inexpensive and rapid replacement if damaged or in need of modulation.

### 5.2.3 Social and Educational Sustainability

Beyond its technical function, the ROV is designed to be a long-lasting educational and research tool for QUT.

– Platform for Future Research: As outlined in the project proposal, a primary goal of this project

is to create a testbed for future research and student projects within the university. The adaptable nature of the ROV ensures it will remain a relevant and valuable asset, facilitating handson learning in marine robotics, control systems, and sensor integration for subsequent student cohorts.

– Knowledge Transfer: The documentation of this project, including this report, serves to trans-

fer knowledge to future teams. The use of widely adopted hardware like the Pixhawk and accessible software frameworks ensures that future students can readily build upon the work completed, fostering a continuous cycle of innovation and learning.

## 6 Resources and Stakeholder Engagement

### 6.1 Codes, Regulations, and Standards

Given the project’s current scope as an experimental platform for controlled environments, such as a QUT testing tank, adherence to specific commercial or maritime standards has not been a primary design constraint. Future development, particularly for deployment in natural waterways such as rivers or coastal waters, will require a review and application of relevant standards relevant to marine equipment and environmental protection.

Despite the experimental nature, proactive safety measures aligned with general robotic best practices have been integrated. Notably, a physical emergency stop has been incorporated into the operator control unit. This feature, absent in many commercial off-the-shelf ROV kits like the BlueROV2, provides a reliable, failsafe method to de-energise the thrusters, significantly enhancing operator and equipment safety during testing.

Furthermore, the use of high-energy Lithium Polymer (LiPo) batteries introduces specific hazards.

All handling, charging, and storage procedures for these batteries will strictly adhere to Queensland University of Technology (QUT) regulations for on-campus laboratory work. These protocols are ex-

plicitly addressed and managed within the project’s formal risk assessment to ensure safe operation.

### 6.2 Stakeholder Input

The project’s direction and progress have been significantly shaped by continuous input from key stakeholders. This collaborative approach ensures the project remains aligned with its objectives, technically sound, and compliant with safety protocols.

### 6.2.1 Primary Stakeholders

Tobias Fischer (Project Supervisor): Mr. Fischer’s role has been crucial in the conceptual and design

phases of the project. His expert evaluation of design iterations and proposals for alternative simulation and modelling approaches have been instrumental. This guidance has been key to validating the design, particularly in balancing the competing constraints of vehicle size and operational runtime, ensuring the final product will meet its core performance targets.

S9 Workshop Technicians: The technical staff at the S9 workshop have provided essential logistical

and safety oversight. Their contributions to sourcing and ordering components have been vital for maintaining the project schedule. Furthermore, their expertise in evaluating the safety of critical systems has been indispensable. A notable instance was their input regarding the use of a highdischarge LiPo battery. Their requirement for a detailed risk assessment prior to the battery’s procurement has reinforced a safety-first culture within the project, ensuring all component selections are rigorously justified and safely implemented.

### 6.2.2 Future Stakeholders

As the project transitions from initial development (Phase 1) into prototyping and testing (Phase 2-3),

the scope of stakeholder engagement will expand.

QUT Facilities and Personnel: Preparations will be made to engage with the facility managers of the

QUT pool and to induct secondary operators, such as Scarlet Raine, who will be involved in future testing.

Collaborating Research Teams: The ROV is being developed as a potential payload-carrying platform for other research groups. Discussions with Tobias Fischer’s other research teams are planned for Phase 3. These engagements will be critical for demonstrating the vehicle’s capabilities and its effectiveness as a tool for their specific applications, which will directly influence the project’s overall impact and potential for future use.

## 7 Conclusion

This report has detailed the significant progress achieved in the initial phase of the small-scale Remotely Operated Vehicle (ROV) development project. The primary objectives of this phase—comprehensive

literature review, detailed mechanical and electrical design, and component procurement—have
been successfully met. A robust literature review has informed a set of key design themes, guiding the project towards established and effective methodologies in ROV construction.

The mechanical design, finalised in CAD and visualized in Figure 4, provides a compact and modular frame centred around a 3-inch series watertight enclosure. The vectored thruster configuration has been selected to reduce power requirements and meet size constraints. All major electronic components, including the Pixhawk 6X flight controller and APISQUEEN U2 MINI thrusters, have been specified and sourced, as documented in the Bill of Materials. A thorough power budget analysis confirms the theoretical viability of the system, estimating an operational runtime of approximately 30 minutes with the selected 5200mAh LiPo battery under typical cruising conditions. With the design finalised and the majority of components now on hand, the project is well-positioned to transition from the theoretical design phase to the physical assembly and integration phase.

## 8 Future Work

The subsequent stages of the project will focus on the physical realisation and empirical validation of the designed system. The work is divided into two distinct phases: system integration and testing.

### 8.1 Phase 2: Assembly and System Integration

The immediate next step involves the complete physical assembly of the ROV. This will begin with the construction of the aluminium frame and the mounting of the thrusters and watertight enclosure. Concurrently, the internal electronics tray will be assembled, integrating the Pixhawk 6X, Power Distribution Board (PDB), Fathom-X interface board, and Electronic Speed Controllers (ESCs).

Key tasks in this phase include:

– Mechanical assembly of the frame and propulsion system.

– Wiring of all internal electronic components, ensuring correct power and signal paths.

– Installation and sealing of the cable penetrators for the thrusters and tether.

– Flashing the Pixhawk controller with the ArduSub firmware and performing initial "on-the-

bench" configuration and sensor calibration.

– Establishing a successful communication link between the topside control station and the ROV

via the Fathom-X tether interface boards.

– Simulating the ROV in a virtual environment using ROS2 and Gazebo to validate the control

algorithms and buoyancy behaviour prior to physical testing.

– Conducting a comprehensive review of the risk assessment to ensure all new hazards intro-

duced during assembly are adequately mitigated.

– Designing buoyancy modules to achieve neutral buoyancy, based on the final mass properties

of the assembled vehicle.

### 8.2 Phase 3: Testing, Tuning, and Deployment

Once assembly is complete, the project will enter the critical testing phase. This will be conducted in a controlled environment, such as QUT and private swimming pools, to ensure safety and allow for iterative adjustments.

The objectives of this phase are:

– Waterproofing and Ballasting: The ROV will undergo initial leak testing. Following this, it will be

carefully ballasted with weights and buoyancy additions to test the simulated neutral buoyancy and a stable trim.

– System Identification: Initial manual control tests will be conducted to gather empirical data on the vehicle’s dynamic response. This data will be crucial for developing an accurate mathematical model of the ROV’s behaviour, which is a prerequisite for advanced controller design.

– Controller Tuning: The Proportional-Integral-Derivative (PID) control loops within the ArduSub/PX4/GCU

firmware will be systematically tuned to provide responsive and stable manual control across
all degrees of freedom.

– Operational Validation: The ROV will be tasked with performing a series of manoeuvres to

validate its performance against the original project objectives. This includes tests for depthholding, heading-holding, and general manoeuvrability.

– Autonomous and Payload Testing: If time permits, basic autonomous waypoint navigation will be tested. Additionally, the vehicle’s capability to carry and operate a simple payload, such as a camera or environmental sensor, will be evaluated.

– Documentation and Handover: Comprehensive documentation of the assembly, configura-

tion, and testing procedures will be compiled. This will ensure that future users can effectively operate and maintain the ROV platform.

Successful completion of these phases will result in a fully operational and tested ROV platform, ready for future research and demonstration applications.

## References

[1] Ali, A. F. and Arshad, M. R. (2017). Design and development remotely operated vehicle for anode ship hull inspection. In 2017 IEEE 7th International Conference on Underwater System Technology: Theory and Applications (USYS), pages 1–5.
[2] Anwar, B. M. M., Ajim, M. A., and Alam, S. (2015). Remotely operated underwater vehicle with surveillance system. In 2015 International Conference on Advances in Electrical Engineering (ICAEE), pages 255–258.
[3] Aras, M. S. M., Azis, F. A., Teck, L. W., Abdullah, S. S., and Rahman, A. F. N. A. (2015). System identification of a prototype small scale rov for depth control. In 2015 10th Asian Control Conference (ASCC), pages 1–6.
[4] Australian Competition & Consumer Commission (ACCC) (2022). Lithium-ion batteries issues

paper.

[5] Binugroho, E. H., Sanggar Dewanto, R., and Pramadihanto, D. (2018). erov: Preliminary design of 5 dof rov using 6 thrusters configuration. In 2018 International Electronics Symposium on Engineering Technology and Applications (IES-ETA), pages 281–287.
[6] Choi, H., Chung, S., Park, H., and Seo, J. (2012). Design and control of a convertible rov. In 2012 Oceans - Yeosu, pages 1–7.
[7] Coccolo, E., Delea, C., Steinmetz, F., Francescon, R., Signori, A., Au, C. N., Campagnaro, F., Schneider, V., Favaro, F., Oeffner, J., Renner, B.-C., and Zorzi, M. (2023). System architecture and communication infrastructure for the robovaas project. IEEE Journal of Oceanic Engineering, 48(3):716 –
739. Cited by: 14.
[8] Engineers Australia (2019). Code of ethics and guidelines on professional conduct.
[9] Jayasundere, N. and Gunawickrama, S. (2016). Underwater rov with fuzzy logic motion control. In 2016 IEEE International Conference on Information and Automation for Sustainability (ICIAfS),

pages 1–6.

[10] Jorge, V. A. M., Gava, P. D. d. C., Silva, J. R. B. F., Mancilha, T. M., Vieira, W., Adabo, G. J., and Nascimento, C. L. (2021). Vita1: An unmanned underwater vehicle prototype for operation in underwater tunnels. In 2021 IEEE International Systems Conference (SysCon), pages 1–8.
[11] K, J., S M, R., S V, S., and K, K. (2023). Remotely operated underwater vehicle (rov). In 2023 2nd International Conference on Advancements in Electrical, Electronics, Communication, Computing and Automation (ICAECA), pages 1–4.

[12] Khoirunnisa, H., Abadi, S. C., Anggraeni, P., and Rudi (2024). Polrov (polman education platform of underwater robot) monitoring navigation design using pid controller method. In 2024 IEEE International Conference on Computing (ICOCO), pages 225–230.
[13] Kopman, V., Cavaliere, N., and Porfiri, M. (2012). Masuv-1: A miniature underwater vehicle

with multidirectional thrust vectoring for safe animal interactions. IEEE/ASME Transactions on Mechatronics, 17(3):563–571.

[14] Laidani, A., Boudria, M., Faci, I., Bouhamri, A., Kebdani, O., Rahmoun, L., Bellahcene, Z., and Bouhamida, M. (2022). Design and modeling of a low-cost observation class rov for dam inspection. In 2022 2nd International Conference on Advanced Electrical Engineering (ICAEE), pages 1–6.
[15] Mai, C., Benzon, M. v., Sørensen, F. F., Klemmensen, S. S., Pedersen, S., and Liniger, J. (2022).

Design of an autonomous rov for marine growth inspection and cleaning. In 2022 IEEE/OES Autonomous Underwater Vehicles Symposium (AUV), pages 1–6.

[16] Martins, A., Almeida, J., Almeida, C., Matias, B., Kapusniak, S., and Silva, E. (2018). Eva a hybrid

rov/auv for underwater mining operations support. In 2018 OCEANS - MTS/IEEE Kobe Techno-Oceans (OTO), pages 1–7.

[17] Marzbanrad, A., Sharafi, J., Eghtesad, M., and Kamali, R. (2011). Design, construction and control of a remotely operated vehicle (rov). Volume 7: Dynamic Systems and Control; Mechatronics and Intelligent Machines, Parts A and B.
[18] MAVLink (2009). Introduction · mavlink developer guide.
[19] Mintchev, S., Donati, E., Marrazza, S., and Stefanini, C. (2014). Mechatronic design of a miniature underwater robot for swarm operations. In 2014 IEEE International Conference on Robotics and Automation (ICRA), pages 2938–2943.
[20] Qi, H., Cao, X., Lv, L., Cong, Z., Lin, L., and Zhang, D. (2020). A design of high mobility auv cost $325. In 2020 IEEE/OES Autonomous Underwater Vehicles Symposium AUV, pages 1–3.
[21] Segovia Ramírez, I., Bernalte Sánchez, P., Papaelias, M., and García Márquez, F. P. (2021). Au-

tonomous underwater vehicles and field of view in underwater operations. Journal of Marine Science and Engineering, 9:277.

[22] Sujan, M., Howlader, J., Alam, M., and Tapu, M. A. I. (2024). Structure design of underwater micro robot. Modern Mechanical Engineering, 14:12–24.
[23] Tang, J., Chen, Z., Fu, B., Lu, W., Li, S., Li, X., and Ji, X. (2024). Rov6d: 6d pose estimation

benchmark dataset for underwater remotely operated vehicles. IEEE Robotics and Automation Letters, 9(1):65–72.

[24] Ulu, C., Canbak, O., Altunkaya, M. U., Taşkin, H., and Yayla, S. (2017). Development of the marmarov remotely operated underwater vehicle system. In 2017 International Artificial Intelligence and Data Processing Symposium (IDAP), pages 1–6.
[25] Vasileiou, M., Manos, N., and Kavallieratou, E. (2021). A low-cost 3d printed mini underwater vehicle: Design and fabrication. In 2021 20th International Conference on Advanced Robotics (ICAR), pages 390–395.

[26] Wettergreen, D., Gaskett, C., and Zelinsky, A. (1999). Autonomous guidance and control for an underwater robotic vehicle. In Proceedings of the International Conference on Field and Service Robotics (FSR’99), Pittsburgh, USA.
[27] Yildiz, Ö., Gökalp, R. B., and Yilmaz, A. E. (2009). A review on motion control of the underwater

vehicles. In 2009 International Conference on Electrical and Electronics Engineering - ELECO 2009,

pages II–337–II–341.

[28] Yoerger, D. R., Curran, M., Fujii, J., German, C. R., Gomez-Ibanez, D., Govindarajan, A. F., How-

land, J. C., Llopiz, J. K., Wiebe, P. H., Hobson, B. W., Katija, K., Risi, M., Robison, B. H., Wilkinson,
C. J., Rock, S. M., and Breier, J. A. (2018). Mesobot: An autonomous underwater vehicle for tracking and sampling midwater targets. In 2018 IEEE/OES Autonomous Underwater Vehicle Workshop (AUV), pages 1–7.
[29] Zain, Z. M., Noh, M. M., Ab Rahim, K. A., and Harun, N. (2016). Design and development of an x4-rov. In 2016 IEEE International Conference on Underwater System Technology: Theory and Applications (USYS), pages 207–211.
[30] Zavari, S., Heininen, A., Aaltonen, J., and Koskinen, K. T. (2016). Early stage design of a spherical underwater robotic vehicle. In 2016 20th International Conference on System Theory, Control and Computing (ICSTCC), pages 240–244.

## A Project Timeline

The project timeline is detailed in the Gantt chart below. The schedule outlines the key phases from the initial proposal through to the planned final testing. Phase 1, encompassing literature review, design, and procurement, has been successfully completed. The project is currently at the beginning of Phase 2.

GANTT CHART

PROJECT TITLE | COMPANY NAME | QUT
PROJECT MANAGER | DATE | 16/10/2025
Sem 2 2025 | Break | Sem 1 2026
# | Task | W1 | W2 | W3 | W4 | W5 | W6 | W7 | W8 | W9 W10W11W12W13W14W15 | W1 | W2 | W3 | W4 | W5 | W6 | W7 | W8 | W9 W10W11W12W13W14W15 | W1 | W2 | W3 | W4 | W5 | W6 | W7 | W8 | W9 W10W11W12W13W14W15

1 | Phase 1
1.1 | Research Papers and Articles
1.1.1 | Research componets and compatibility
1.2 | Research componets avaliability
1.3 | write project proposal
1.4 | Search for component models
1.5 | Create inital design
1.6 | Refine Inital design
1.7 | write progress report
2 | Phase 2
2.1 | Export Design to urdf
2.2 | Simulate Buoyancy and control
2.3 | Refine and improve design
2.4 | Construct prototype
2.5 | Document Progress
3 | Phase 3
3.1 | Inital tests on prototype
3.2 | Manual Input testing
3.2.1 | Program and Design Control Setup
3.2.2 | Add Autonomous pathing
3.3 | Document Progress
3.3.1 | Report findings and present

6

5

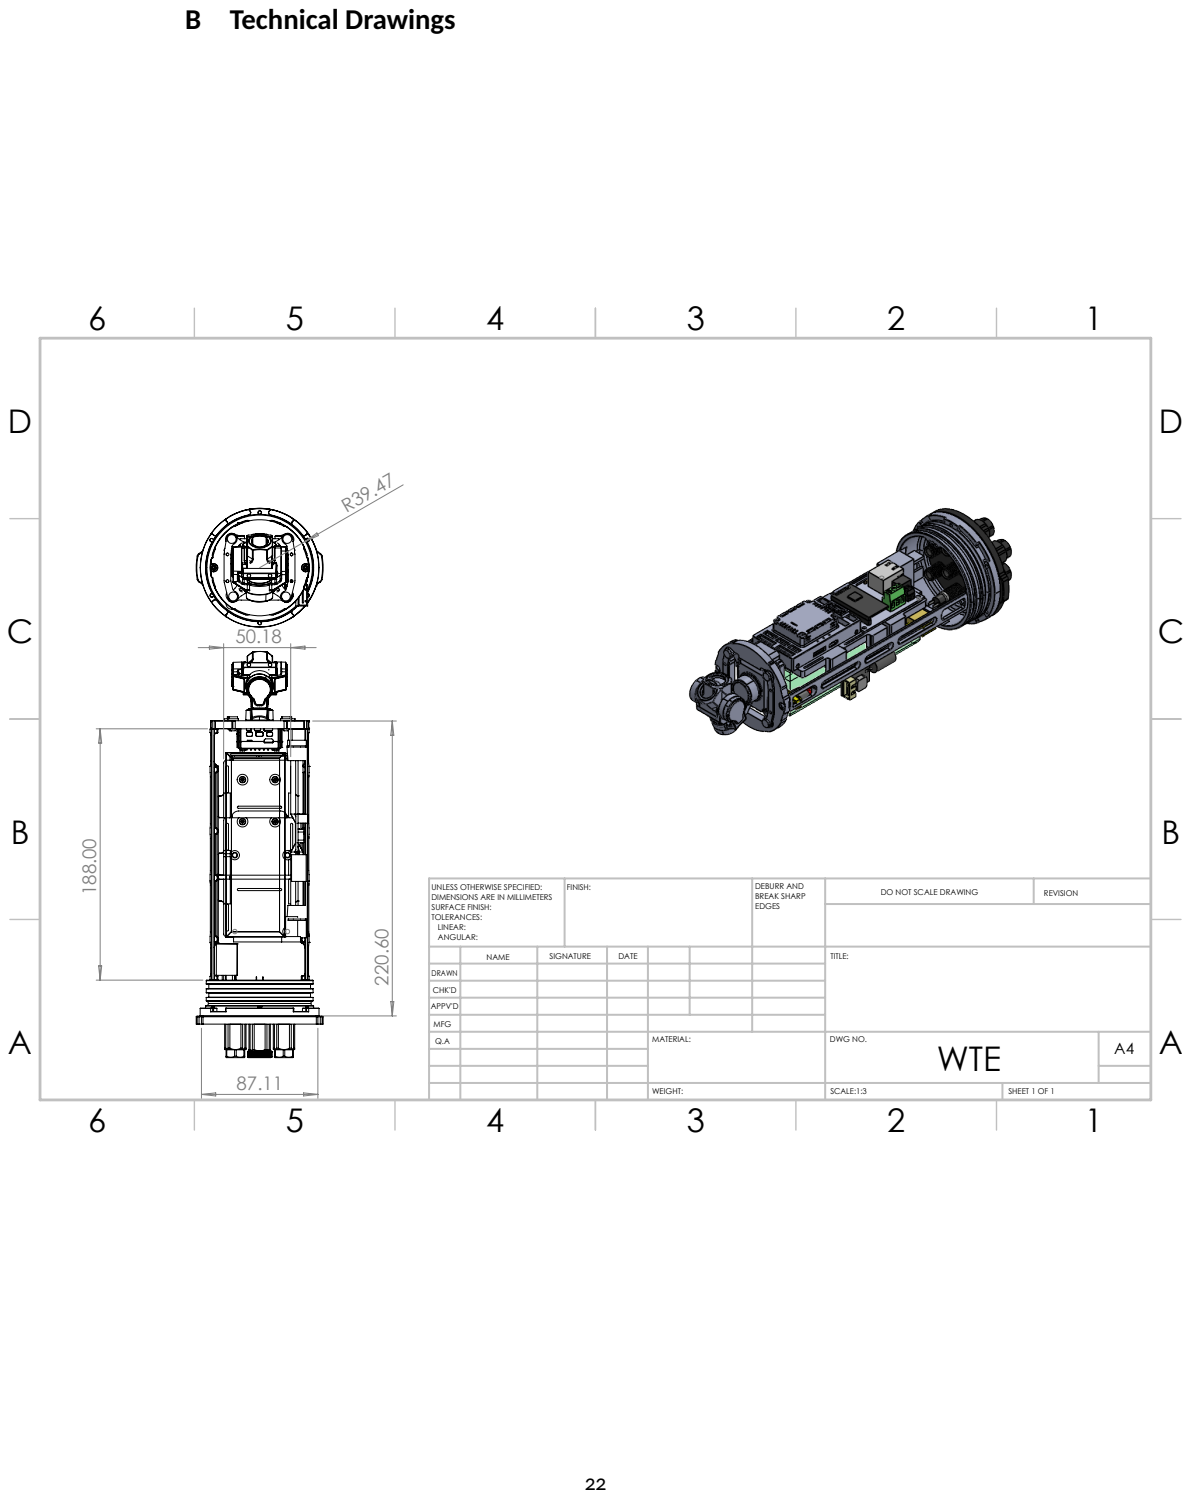
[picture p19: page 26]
FINISH:; DEBURR AND; BREAK SHARP EDGES; DO NOT SCALE DRAWING; REVISION; SCALE:1:3; SHEET 1 OF 1; WEIGHT:; B Technical Drawings

UNLESS OTHERWISE SPECIFIED:
DIMENSIONS ARE IN MILLIMETERS
SURFACE FINISH:
TOLERANCES:
LINEAR:
ANGULAR:

NAME | SIGNATURE | DATE | | | | TITLE:

DRAWN
CHK'D
APPV'D
MFG
Q.A | | | | MATERIAL: | DWG NO. WTE | A4

2

1

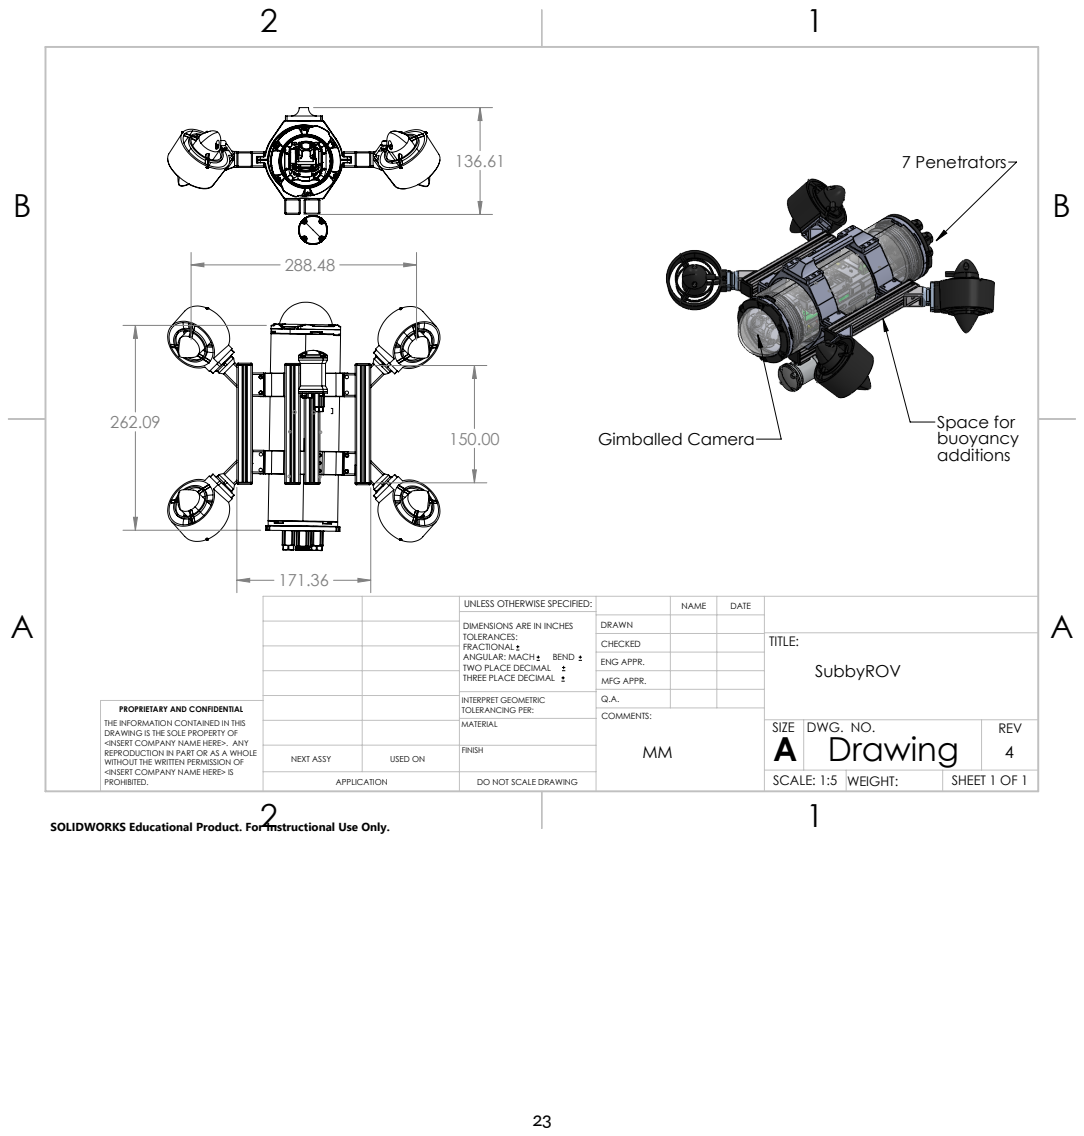
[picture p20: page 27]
Space for buoyancy additions; 7 Penetrators; Gimballed Camera; Drawing; DWG. NO.; REV; SIZE; COMMENTS:; MATERIAL

UNLESS OTHERWISE SPECIFIED: | | NAME | DATE
DIMENSIONS ARE IN INCHES TOLERANCES: FRACTIONAL ANGULAR: MACH BEND TWO PLACE DECIMAL THREE PLACE DECIMAL | DRAWN

CHECKED | | | TITLE: SubbyROV

ENG APPR.
MFG APPR.

INTERPRET GEOMETRIC TOLERANCING PER: | Q.A.

PROPRIETARY AND CONFIDENTIAL
THE INFORMATION CONTAINED IN THIS
DRAWING IS THE SOLE PROPERTY OF
<INSERT COMPANY NAME HERE>. ANY
REPRODUCTION IN PART OR AS A WHOLE
WITHOUT THE WRITTEN PERMISSION OF
<INSERT COMPANY NAME HERE> IS
PROHIBITED.

NEXT ASSY | USED ON | FINISH

APPLICATION | DO NOT SCALE DRAWING | | SCALE: 1:5 | WEIGHT: | SHEET 1 OF 1

SOLIDWORKS Educational Product. For Instructional Use Only.

## C BOM (Full)

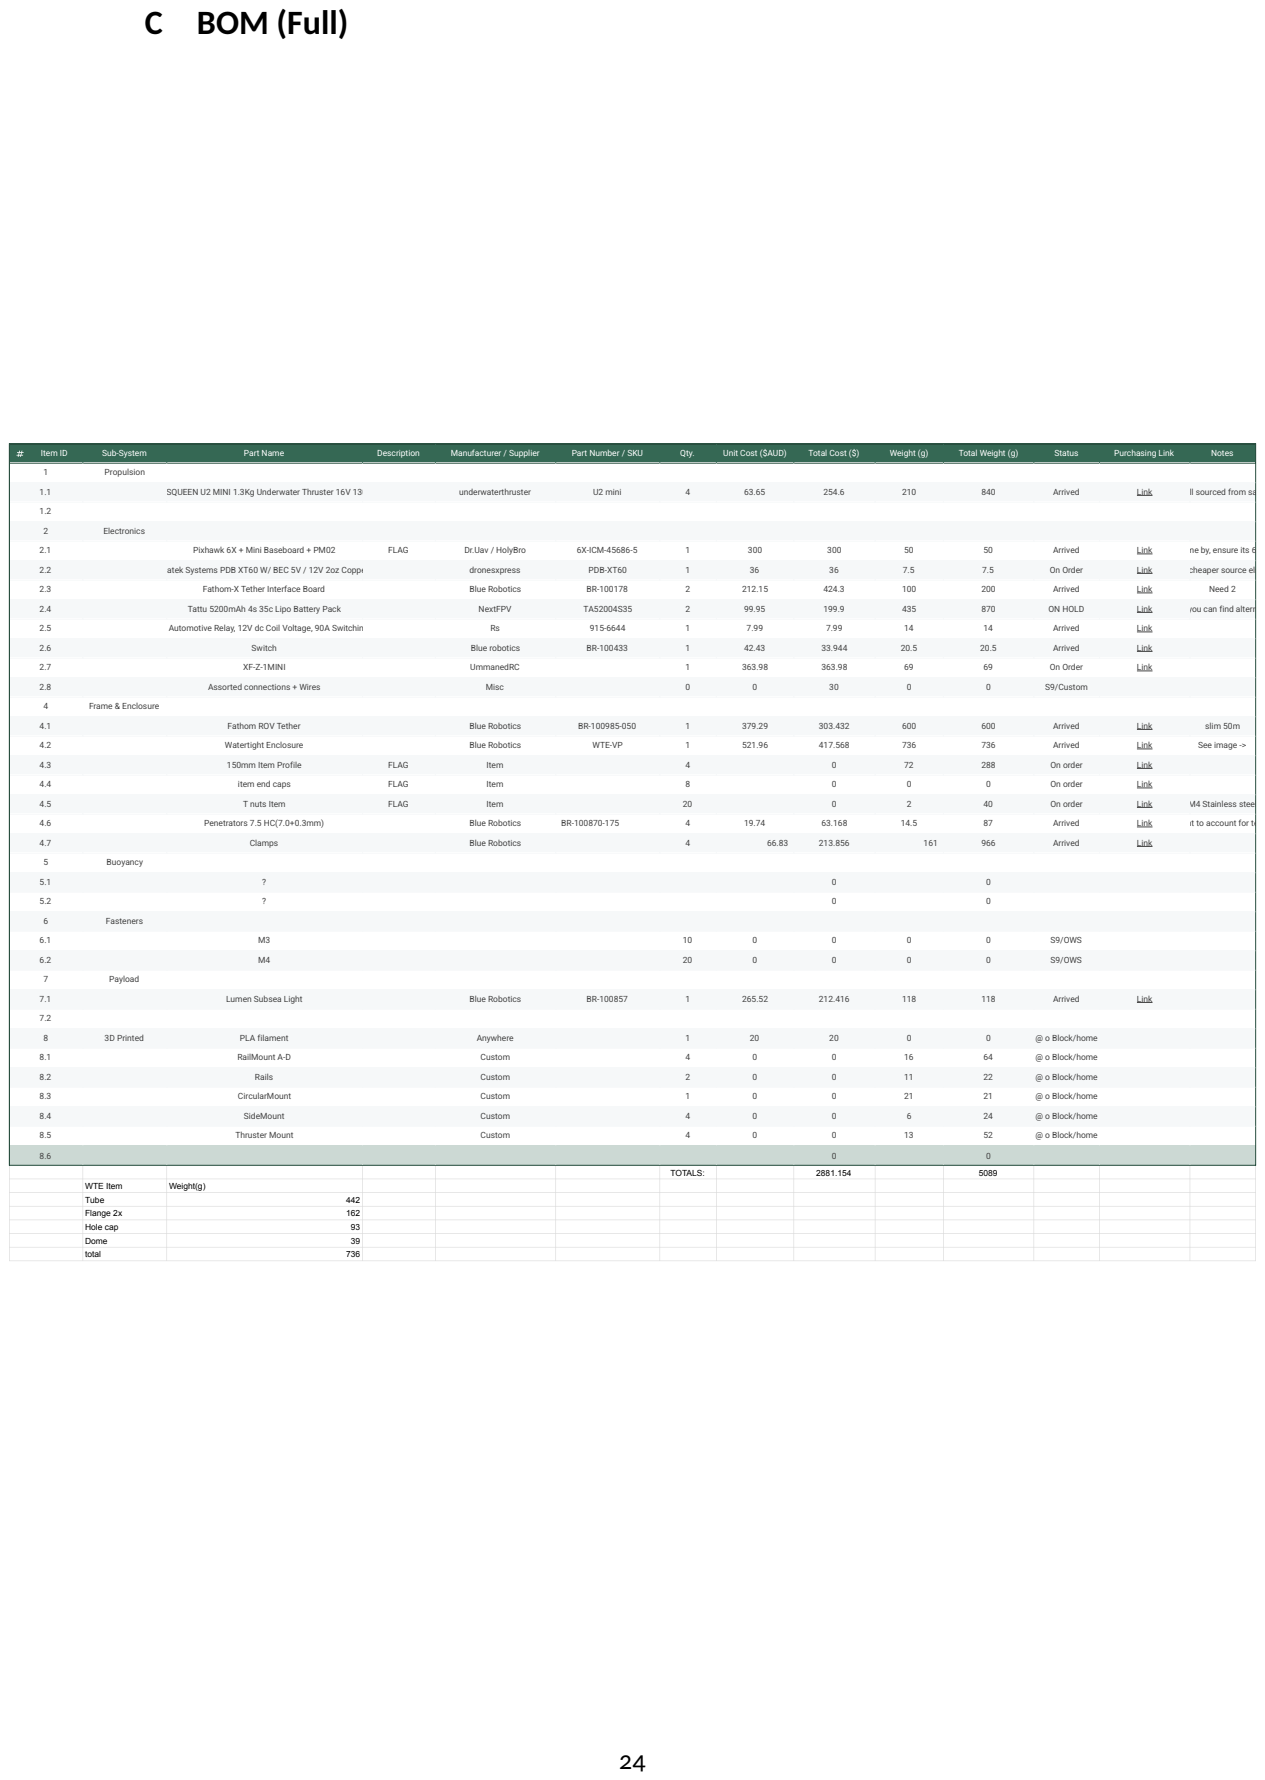
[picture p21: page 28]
Matek Systems PDB XT60 W/ BEC 5V / 12V 2oz Copper; dronesxpress; PDB-XT60; On Order; Link if found cheaper source elsewhere; TOTALS:; 5089 WTE Item; Weight(g) Tube; 442 Flange 2x; 162 Hole cap; 93 Dome; total

Item ID | Sub-System | Part Name | Description | Manufacturer / Supplier | Part Number / SKU | Qty. | Unit Cost ($AUD) | Total Cost ($) | Weight (g) | Total Weight (g) | Status | Purchasing Link | Notes

1 | Propulsion

1.1 | APISQUEEN U2 MINI 1.3Kg Underwater Thruster 16V 130W | | | underwaterthruster | U2 mini | 4 | 63.65 | 254.6 | 210 | 840 | Arrived | Link

2 | Electronics

2.1 | | Pixhawk 6X + Mini Baseboard + PM02 | FLAG | Dr.Uav / HolyBro | 6X-ICM-45686-5 | 1 | 300 | 300 | 50 | 50 | Arrived | Link

2.3 | | Fathom-X Tether Interface Board | | Blue Robotics | BR-100178 | 2 | 212.15 | 424.3 | 100 | 200 | Arrived | Link | Need 2

2.4 | | Tattu 5200mAh 4s 35c Lipo Battery Pack | | NextFPV | TA52004S35 | 2 | 99.95 | 199.9 | 435 | 870 | ON HOLD | Link

2.5 | Durakool Plug In Automotive Relay, 12V dc Coil Voltage, 90A Switching Current, SPDT | | | Rs | 915-6644 | 1 | 7.99 | 7.99 | 14 | 14 | Arrived | Link

2.6 | | Switch | | Blue robotics | BR-100433 | 1 | 42.43 | 33.944 | 20.5 | 20.5 | Arrived | Link

2.7 | | XF-Z-1MINI | | UmmanedRC | | 1 | 363.98 | 363.98 | 69 | 69 | On Order | Link

2.8 | | Assorted connections + Wires | | Misc | | 0 | 0 | 30 | 0 | 0 | S9/Custom

4 | Frame & Enclosure

4.1 | | Fathom ROV Tether | | Blue Robotics | BR-100985-050 | 1 | 379.29 | 303.432 | 600 | 600 | Arrived | Link | slim 50m

4.2 | | Watertight Enclosure | | Blue Robotics | WTE-VP | 1 | 521.96 | 417.568 | 736 | 736 | Arrived | Link | See image ->

4.3 | | 150mm Item Profile | FLAG | Item | | 4 | | 0 | 72 | 288 | On order | Link

4.4 | | item end caps | FLAG | Item | | 8 | | 0 | 0 | 0 | On order | Link

4.5 | | T nuts Item | FLAG | Item | | 20 | | 0 | 2 | 40 | On order | Link | M4 Stainless steel

4.6 | | Penetrators 7.5 HC(7.0+0.3mm) | | Blue Robotics | BR-100870-175 | 4 | 19.74 | 63.168 | 14.5 | 87 | Arrived | Link

4.7 | | Clamps | | Blue Robotics | | 4 | 66.83 | 213.856 | 161 | 966 | Arrived | Link

5 | Buoyancy

6 | Fasteners

6.1 | | M3 | | | | 10 | 0 | 0 | 0 | 0 | S9/OWS

6.2 | | M4 | | | | 20 | 0 | 0 | 0 | 0 | S9/OWS

7 | Payload

7.1 | | Lumen Subsea Light | | Blue Robotics | BR-100857 | 1 | 265.52 | 212.416 | 118 | 118 | Arrived | Link

8 | 3D Printed | PLA filament | | Anywhere | | 1 | 20 | 20 | 0 | 0 | @ o Block/home

8.1 | | RailMount A-D | | Custom | | 4 | 0 | 0 | 16 | 64 | @ o Block/home

8.2 | | Rails | | Custom | | 2 | 0 | 0 | 11 | 22 | @ o Block/home

8.3 | | CircularMount | | Custom | | 1 | 0 | 0 | 21 | 21 | @ o Block/home

8.4 | | SideMount | | Custom | | 4 | 0 | 0 | 6 | 24 | @ o Block/home

8.5 8.6 | | Thruster Mount | | Custom | | 4 | 0 | 0 0 | 13 | 52 0 | @ o Block/home

Item ID | Sub-System | Part Name | Description | Manufacturer / Supplier | Part Number / SKU | Qty. | Unit Cost ($AUD) | Total Cost ($) | Weight (g) | Total Weight (g) | Status | Purchasing Link | Notes
Tether Weight | Item weight
Ratio kg/m | 0.012 | 0.48 Amount m | 50 | 0.15 Total g | 600 | 72

Customer Details:-
Owner: Josh Hecke (joshua.hecke@connect.qut.edu.au)

### Risk Assessment : 18339 (Pending Endorsement)

Review: Yes

Haz
ID
| Hazard | Cause of Harm | What could go wrong | L | C | Risk Score

Hide
Items
79996 | Slip-Trip-Fall | Slippery surfaces | Slipping getting in and out of boat, on boat ramps or on shore close to water. | Possible | Minor | Low
| | Control | Hierachy: Administration Control: Assess conditions before moving around location. Must wear suitable footwear according to location (e.g. shoes, or wet booties). Only hop onto boat once fully secured. Do not run. Use multiple people to carry equipment on shore or loading boat.
79997 | Plant and Equipment | Operation | Rotating propellers - cuts, injuries, equipment in motion. | Unlikely | Minor | Low
| | Control | Hierachy: Engineering Control: For the BlueRov, the remote operator interface controls the motors and touching any control will disable the system and put it into idle mode.
| | Control | Hierachy: Isolation Control: On the BlueRov, the motors have shrouds minimizing the possibility of accidental contact with the propellers.

Hazard Details:-

Campus | Building | Floor | Room | Addional Info
Off Campus | | | | These are operated on-water in the field at approved locations(A key example would be QUT Pool or Personal Pool)
Gardens Point | S Block | Level 11 | 1145-Post-Graduate Lab. | Mobile Robots Lab Soldering Station

Location Details:-

Email: joshua.hecke@connect.qut.edu.au | Endorsement: Yes

Assessment Type: Plant/Equipment
Division/Faculty: Faculty of Engineering School/Depart: School of Electrical Engineering & Robotics | QUT Team: School of Electrical Engineering & Robotics
| QUT SubTeam:
Start Date: 8/25/2025

Title: Design of small scale Remotely Operated Vehicle - Underwater Robot
Description: This is an risk assessment to support the design of a new small scale ROV on campus.

The primary risks relate to electrical safety during development, manual handling, operation, electrical safety including charging and packing and storage for travel.

Only Tobias Fischer, Joshua Hecke and Scarlet Raine will be able to operate this device during development and testing, due to its experimental nature. Other team members can operate this vehicle after contacting said operators and receiving a induction.

Main Risks-
*5200mAh 14v LIPO Battery Use and Handling*
*Operation and Handling around water*
IF USED
*Safe use and Storage of Dichtol Waterproofing*
Ensure-S9 lab techs are aware of LIPO presence if battery is on campus for safe storage and charging.

In addition to this risk assessment, Approval of any commercial areas(i.e qut pool) needs to be organized with the appropriate body accordingly.

Est End Date: 6/25/2026

MAPS ID:

## D Full Risk Assessment

79998 | Manual Tasks | Posture - sustained/awkward/static | During deployment on shore/surface:
- awkward posture (kneeling, squatting, balancing etc)
- bending/twisting
- duration of work
- load handling
- long standing/sitting
- muscular force exerted
- repetitive movement
Unlikely | Moderate | Medium
| | Control | Hierachy: Other Control: Take regular breaks, Keep area tidy, Position body (and maneuver boat) to life appropriately Use the handles on the equipment
79999 | Electrical | <50 volts AC/<120 volts DC | Fire or damage to batteries due to charging or discharging | Possible | Minor | Low
| | Control | Hierachy: Administration Control: After being approved/checked by lab tech, operators can now keep batteries on their person and conduct charging in designated charging areas in s11.
| | Control | Hierachy: Administration Control: Follow the operating manual for the chargers and ASVs
| | Control | Hierachy: Engineering Control: Only use official supplier and tagged chargers.
| | Control | Hierachy: PPE Control: Ensure batteries are charged and transported in lipo safe bags
| | Control | Hierachy: PPE Control: Fire extinguisher and/or fire blanket at working site.
80000 | Other | General assembly, building and installation of sensors and payloads.
- injury due to misuse of tools
- pinch points
| | | | Possible | Minor | Low
| | Control | Hierachy: Administration Control: Standard operating procedures General assembly of the main hull and location of pinch points are clearly marked. An online SOP for the ASVs is maintained (QUT wiki). Each participant is aware and has access to these manuals and the latest is attached to this risk assessment.
| | Control | Hierachy: Administration Control: Training and education Ensure each participant is appropriately trained for the tools and equipment they are using and if required inducted into the work-zone.
80001 | Fieldwork | Other | Public hazards Unauthorized persons approach the vessel during operation such as swimmers or canoes.
- knocking someone into the water
- collision with a swimmer
- collision with another vessel
- public interfering with the vessel
| | | | Rare | Minor | Negligible
Control | Hierachy: Administration Control: Standard Operating Procedures Follow the SOP and exception permit requirements for notifying the public and locations for operation.
Control | Hierachy: Engineering Control: The overall mass is to be kept low so that there is minimal kinetic energy in any collisiot. Ensure all motors are shrouded and the shrouds are intacts.
Control | Hierachy: Isolation Control: Remote control devices All vessels have at least one level of wireless estop of wireless e-Stops. For the BlueRov2, the first is a hardwored heartbeat which must be maintained from the shore to allow power to the motors. The other is the remote control unit (e.g., RC controller or tablet) which can manually overide the computer and when switched off will also trigger the e-Stop. 27

80001 | | Control | Hierachy: Isolation Control: The test location will be selected (moved within the site) to areas where there are no public visible or planned to be in the area. Conditions of applicable permits will be followed. If possible, on inland water storages, select sites that have no public access and seek approval from the land owners.
80003 | Fieldwork | Other | Working near water
- drowning
- slipping and falling
- cuts from debris in the mud (e.g. broken glass, sharp rocks
Unlikely | Major | Medium
| | Control | Hierachy: Administration Control: Prepare and train for emergency response Details of the trained first-aiders made aware to the team on arrival at site as well as the location (in-vehicle) of the emergency contacts and closest hospital.
| | Control | Hierachy: Administration Control: Standard operating procedures The captain on boarding the boats will advise the team and crew of the standard operating procedures for all aspects of working at sea. This includes location of life- jackets, procedure for man overboard. These procedures are documented on-board the vessels and placards are placed around the vessel. For people that cannot swim or are uncomfortable around the water, they are encouraged to wear life-jackets whenever working near the edge of the boat.
| | Control | Hierachy: Administration Control: WAM-V SOP - Initially, the boat will be assembled on the waters edge following a visual inspection of the area and assessment of water depth. With a bow rope attached, the boat will be carried until the the stern is in the water (approximately 5 inches deep) and then pushed from the bow until completely in the water. Recovery will involve remote controlling the boat to the shore bow first, dragging the boat back onto shore (lifting the bow slightly) until the rear handles are at the shoreline and then lifted onto shore. This means that only shallow water sites are needed
| | Control | Hierachy: PPE Control: Each participant will wear enclosed footwear to allow walking at the water edge without risk of cutting feet due to debris and with enough grip to minimise slipping.
| | Control | Hierachy: PPE Control: Ensure suitable and fit for purpose life-jackets are available for all personal. These must be worn whilst on the boats when required by the skippers and vessels operating procedures.
80004 | Manual Tasks | Setting up equipment/furniture | Strains and sprains. Lifting equipment and transport cases for launching from shore. | Unlikely | Minor | Low
| | Control | Hierachy: Administration Control: Assess weight and size of load. Use more people to lift if awkward, slippery or unable to lift. Use trolleys on campus.
| | Control | Hierachy: Other Control: General assembly of the main hull and location of pinch points are detailed in the manufacturers manual (see attachment). Each participant is aware and has access to this manual.
80005 | Electrical | <50 volts AC/<120 volts DC | General hazard: Working with ultra low voltage DC (5-24Volts) Electrical equipment such as electric motors and sensors.
- low voltage shock
- burns
- electrical fires
| | | | Possible | Minor | Low
Control | Hierachy: Administration Control: Ensure all participants working with low-voltage electrical are trained in the use of the equipment and have the appropriate laboratory inductions if required to undertake the work.
Control | Hierachy: Administration Control: Follow procedure for installation and removal of batteries. Ensure the equipment is turned off before installation or removal.

80005 | | Control | Hierachy: Administration Control: Keeping equipment and plant well maintained. Use only fit-for purpose equipment. Ensure all wiring is documented and appropriately labelled where necessary.
| | Control | Hierachy: Isolation Control: Isolation switches and/or quick release plugs/connectors (such as Anderson or XT connectors) for isolating power to the components being worked on.
| | Control | Hierachy: Other Control: Fire extinguisher and/or fire blanket at the work site. Also LiPo safe bags for transporting and charging LiPo batteries
| | Control | Hierachy: PPE Control: Ensure batteries are charged and transported in lipo safe bags
80006 | Other | Loss of robot during missions | - Losing contact with the robot during missions
- Leaking of water into robot
| | | | Unlikely | Minor | Low
| | Control | Hierachy: Administration Control: Standard operating procedures The missions are planned such that the ROV will operate in within a defined range. The ROV are tethered and in loss of power the robot can be located and most likely retrieced using the tether. In the event of leaking of water into the ASV, the robot should have sufficient remaining buoyancy to remain at the surface In the event of a leaking robots, the batteries have been selected to minimize risk of fire or explosion and on recovery the robot will be isolated for up to 3 hours to ensure no fire risk before further handling.
| | Control | Hierachy: Administration Control: The Operation of the ROV in navigable waters are covered under the AMSA Specific Exemption permit. This has requirements in the equipment required such as radios for alerting people in the vacinity, markings and the use of a ground control station (tablets and/or computers).
| | Control | Hierachy: Other Control: The BlueRov have a hearthbeat sent over the teather. The operational status and approximate possition are always known wihin a few meters.
80008 | Electrical | Operation of electrical equipment | Burn, Shock, Breathing in solder fumes | Possible | Minor | Low
| | Control | Hierachy: PPE Control: Ensure Glasses and extraction fan are used when soldering.
| | Control | Hierachy: PPE Control: When handling parts and chemicals ensure gloves are warn and safety gear including masks are worn.
80178 | Chemicals | Handling and use | *This chemical may not be used* Use of non-hazardous dichtol for waterproofing 3d parts. Standard handling risks include inhalation, skin contact, eye contact | Possible | Minor | Low
Control | Hierachy: Administration Control: The chemical will be stored in s9 store when not in use and be lent out when used in s11. To be returned at end of use
Control | Hierachy: Isolation Control: Remove risk by storing in carefully closed container upright with lid on tight

80178 | | Control | Hierachy: Other Control: General information In all cases of doubt, or when symptoms persist, seek medical advice. If unconscious but breathing normally, place in recovery position and seek medical advice.
| | | Following inhalation Remove casualty to fresh air and keep warm and at rest. In case of irregular breathing or respiratory arrest provide artificial respiration.
| | | Following skin contact Remove contaminated, saturated clothing immediately. After contact with skin, wash immediately with plenty of water and soap. Do not use solvents or thinners. Wash contaminated clothing before reuse.
| | | After eye contact Rinse cautiously with water for several minutes. Remove contact lenses, if present and easy to do. Continue rinsing. Seek medical advice immediately.
| | | Following ingestion If swallowed, rinse mouth with water (only if the person is conscious). Seek medical advice immediately. Keep victim calm. Do NOT induce vomiting.
| | | Self-protection of the first aider First aider: Pay attention to self-protection! Most important symptoms and effects, both acute and delayed
| | | Symptoms In all cases of doubt, or when symptoms persist, seek medical advice. Indication of any immediate medical attention and special treatment needed First Aid, decontamination, treatment of symptoms.
| | Control | Hierachy: PPE Control: gloves, eye protection, respiratory protection
80320 | Electrical | Design/modification | Water could enter electrical storage containers causing damage and potential shock. This is due to waterproof seals failing or not being sufficient
Possible | Moderate | Medium
| | Control | Hierachy: Elimination Control: Try to use certified/standard waterproofed containers (BlueRov product) where possible and only use custom made containers where necessary
| | Control | Hierachy: Engineering Control: Ensure all waterproof containers are tested multiple times at the required depth before being used to store components.
83411 | Electrical | Operation of electrical equipment | Lipo Battery 5200mAh 14V -Overcharging- can cause damage and fires -Storage- Storing LiPo batteries in inappropriate temperatures or locations can affect their performance and safety -Thermal Runaway-A dangerous process where a battery overheats and cannot cool down, leading to fire, explosion, and toxic fumes -Physical Damage- Punctures, fractures, or tears in the battery casing can lead to internal short circuits, increasing the risk of fire
Possible | Moderate | Medium
Control | Hierachy: Administration Control: Ensure days notice before any use,s9 techs will prepare accordingly.
Control | Hierachy: Administration Control: For Handling, Lab Techs in s9 control the charging and storage of LIPOs.
| This is non-negotiable as the methods already in place for safe storage, charging and testing.
Control | Hierachy: Elimination Control: Check resistance between battery input terminals and ensure no shorts or low resistance before use to ensure max output is not placed on system.

83411 | | Control | Hierachy: Engineering Control: Before the battery is in operation ensure use in the system doesn't heat up the battery to a safety critical range. This is done through safe testing and calculations to ensure constant high draw causes heat
| Control Hierachy: Engineering Control: Don’t run the battery down below 20% capacity. Control Hierachy: Isolation Control: Ensure when the battery is in use and/or exposed that there is a safe distance/exclusion zone. Especially for initial testing and research.
| | Control | Hierachy: Isolation Control: The LIPO will remain inside a LIPO Bag during transport at all times. Ensure it is collected like this.

Participant
Name

Scarlett Raine (sg.raine@qut.edu.au)

Josh Hecke (joshua.hecke@connect.qut.edu.au)

Tobias Fischer (tobias.fischer@qut.edu.au)

Participant Details:-

Reviewer
Name

Review
Status
Tobias Fischer (tobias.fischer@qut.edu.au) | Pending
Steven Bulmer (steven.bulmer@qut.edu.au) | Pending
Reviewer Details:- | Approver Details:-
| Approver Name
| Dhammika Jayalath (dhammika.jayalath@qut.edu.au)
ID | Approval | Approver Name | Approval Status
21769 | Risk Assessment Endorsment required for Risk Tobias Fischer (tobias.fischer@qut.edu.au) Assessment#18339 Risk Assessment Approval required for Assessment Firuz Zare (f.zare@qut.edu.au) #18339 | | Approved
22118 | | | Cancelled
22165 | Risk Assessment Endorsment required for Risk Assessment#18339 | Tobias Fischer (tobias.fischer@qut.edu.au) | Pending

Approval Details:-

Subject | Note | Category | Created Date | Created By
Reviewer Note | Hi Josh, Overall well done and comprehensive RA!
- I've added Scarlett Raine as a participant as she's leading a lot of
| our marine robotics work, please update description accordingly.
- Other team members need to contact operators + get induction
- Remove everything boat related from the RA (loss of robot, ...),
| this is out of scope for this RA. If boat operation will happen in the future, we'll need to submit a separate RA.
- Need to add water leakage as hazard + appropriate controls;
| describe tank etc.
- Need to provide detailed information on where chemicals will be
| stored (Krishna to advise)
- Need to provide detailed information on where batteries will be
| stored (Krishna to advise)
- Change "low voltage" to "ultra low voltage" to be consistent with
| regulation Let me know if you have any questions. Best, Tobi
Customer Notes | 9/19/2025 10:29:17 AM | Tobias Fischer (tobias.fischer@qut.edu.au)

Note Details:-

Reviewer Note | Happy to accept this for now but maybe some additions would help further readings. Make it clear that the batteries used are not LIPO. I was sent a link to a Li-Ion battery which is a much safer chemistry. I would get Shaun and or S9 involved asap to get him in the loop for chemical purchase and storage. I think ultimately the users will be the ones requesting the chemicals for purchase and then involve S9 for the storage. | Customer Notes | 9/19/2025 10:29:17 AM | Steven Bulmer (steven.bulmer@qut.edu.au)
Endorser Note | Hi Josh, I am happy to endorse this as soon as 1) Scarlett has been added to Project Description, and 2) You consider Steve's comments about chemicals/battery descriptions. Best, Tobi | Customer Notes | 9/19/2025 10:29:17 AM | Tobias Fischer (tobias.fischer@qut.edu.au)

## E Original Literature Review (from Project Proposal)

E.1 Introduction

Unmanned Underwater Vehicles (UUVs) have become indispensable tools for a vast range of applications, including oceanographic surveys, infrastructure maintenance, and military defence [7, 21]. As

technology has advanced, these vehicles have evolved from simple teleoperated platforms into complex autonomous systems capable of executing sophisticated missions [7]. However, the literature re-

veals that a significant portion of research and commercial development has focused on large-scale, work-class vehicles or highly specialised Autonomous Underwater Vehicles (AUVs), which are often financially and logistically inaccessible for educational institutions or rapid prototyping research [25].

This is due to the cost of setting up demonstrations with large scale ROV and larger ROV designs call for larger scale prototyping solutions which may not be realistic. This has created a gap for small-scale, low-cost, and modular ROV platforms that are not only suitable for demonstration but are also powerful enough to serve as testbeds for advanced control and perception algorithms. The aim of this review is to explore the current state-of-the-art in small-scale ROV design by analysing key themes in existing literature, thereby identifying best practices and informing the design methodology for a novel research platform.

E.2 Methodology and Scope

The literature review was conducted using a systematic approach, focusing on peer-reviewed journal articles, conference papers, and technical reports from the last decade. The search was primarily conducted using the database IEEE Xplore, with keywords including "small-scale ROV", "underwater vehicle design", "ROV control systems", and "modular underwater robotics". The review is structured to cover key design themes, hardware and software selections, control system architectures, and system modelling approaches, providing a comprehensive overview of the current state of small-scale ROV research. The scope of this review is limited to reviewing current literature on ROV design methodology and hardware selections.

E.3 Key Design Themes

E.3.1 Chassis and Mechanical Design

The physical architecture of an ROV is a foundational design choice that dictates its hydrodynamic performance, modularity, and durability. The literature presents a clear dichotomy between open-frame and enclosed, torpedo-style chassis designs. Open-frame designs, such as those seen in the KCROV [6], MarmaROV [24], and eROV [5], are praised for their modularity, allowing for easy mount-

ing of sensors, payloads, and thrusters. This configuration simplifies maintenance and is highly adaptable for research platforms. In contrast, streamlined, enclosed hulls are often selected to minimise hydrodynamic drag for greater efficiency and speed, as demonstrated by the MASUV-1 [13] and X4-ROV [29]. The thruster configuration is critical for maneuverability, with designs ranging from underactuated 3-thruster systems providing basic 3-DOF motion [27], to fully actuated 6 or 8 thruster systems enabling full 6 DOF control [15, 17]. The placement of thrusters in a vectored arrangement

is common for achieving high agility, allowing for coupled control of surge, sway, and yaw from a set of horizontal thrusters [11, 25].

E.3.2 Material Selection and Waterproofing

Material selection directly impacts the vehicle’s weight, durability, and operational depth. For low-cost educational platforms like the ArduinoSub and the vehicle proposed by Anwar et al. [2], PVC

and acrylic are common choices due to their affordability and ease of fabrication. For more robust applications, designs progress towards aluminium frames and hulls [6, 21], with high-performance

vehicles intended for deep-sea operation employing materials like carbon fibre and syntactic foam to achieve high strength-to-weight ratios [14]. Waterproofing remains a critical and persistent challenge. Standard solutions include O-ring seals for static enclosures and potted cable penetrators [17].

However, the literature presents several innovative approaches to overcome the limitations of these methods. The Jeff AUV uses a novel non-penetrative magnetic coupling to transmit torque from internal motors to external propellers, completely eliminating the need for a dynamic shaft seal [19]. The design by Tang et al. [23] also highlights custom-developed connectors as a significant improve-

ment over permanently potting electronics, allowing for easier maintenance and repair. For the QUT demonstration ROV, waterproofing will be a key challenge due to its small form factor.

E.3.3 Hardware Selections

Propulsion and Sensing. The choice of thrusters and sensors is dictated by the vehicle’s mission profile and budget. Propulsion systems range from modified low-cost( $50) bilge pumps in bud-

get designs [20] to commercially available, high-performance brushless DC thrusters like the BlueRobotics T200( $350 per unit), which are noted for their power and reliability [5,11]. Sensor suites vary

significantly; educational kits may only include a basic Inertial Measurement Unit (IMU) and a camera [25], while advanced research platforms like EVA and Mesobot are equipped with a comprehensive array of high end high-cost sensors, including Doppler Velocity Logs (DVLs) for measuring velocity relative to the seafloor( $12,500), USBL positioning systems for underwater localization( $3000), and high-resolution waterproofed cameras for visual navigation( $300) [16, 28].

Control Hardware. The selection of onboard electronics reflects a trade-off between cost, compu-

tational power, and development complexity. At the low-cost end of the spectrum, microcontroller based systems are prevalent. The D20-ROV and ArduinoSub, for instance, use an Arduino Mega 2560 as the central brain, which is sufficient for basic manual control and sensor interfacing [1, 27]. For

more advanced capabilities, single-board computers like the Raspberry Pi are frequently adopted, as seen in the BlueRov2 and PolROV designs, providing a Linux-based environment capable of handling networking, video streaming, and more complex algorithms [11,12]. High-performance vehicles

designed for significant autonomy, such as EVA and Mesobot, employ multi-computer architectures with powerful CPUs and dedicated GPUs (e.g., Nvidia Jetson TX2) to process large volumes of sensor data in real-time [16, 28].

E.3.4 Software and Communication Frameworks

The software stack and communication architecture are integral to the ROV’s functionality. For complex, modular systems, the ROS is the framework of choice, as seen in the Autonomous ROV for Marine Growth and the EVA hybrid vehicle [15, 16]. ROS is valued for its extensive libraries, hardware

drivers, and robust inter-process communication, which significantly accelerates development time.

On simpler platforms, custom firmware is often developed in C++ within the Arduino IDE or using Python on a Raspberry Pi [25]. Open-source firmware like ArduSub, used in the VITA1 prototype,

provides a powerful and well-supported alternative to developing a control system from scratch [10]. Communication is almost universally handled via a physical tether for ROVs, which provides

both power and a high-bandwidth data link. This link is typically Ethernet over twisted pairs, though high-end systems may use fibre optics for greater bandwidth and distance [14].

E.3.5 Control System Architectures

Control strategies for underwater vehicles have matured from direct teleoperation to sophisticated autonomous behaviours [27]. The foundational control method discussed in much of the literature

is the PID controller, used for fundamental tasks like depth-hold and heading-hold in vehicles such as the PolROV and Ariana-I [12, 17]. These controllers are well-understood and relatively simple to

implement. However, due to the highly non-linear dynamics of underwater vehicles, more advanced techniques are often required for robust performance, especially in the presence of external disturbances like currents [27]. To address this, some designs implement Sliding Mode Control (SMC) for its robustness to parameter uncertainties [27], or Fuzzy Logic controllers which do not require a precise mathematical model of the system [9]. The Kambara AUV represents the cutting edge, employing

model-free reinforcement learning to allow the controller to learn the vehicle’s dynamics through trial and error, avoiding the need for an explicit model altogether [26].

E.3.6 System Modelling Approaches

The development of a control system is often preceded by system modelling to simulate and predict the vehicle’s behaviour. A key distinction in the literature is the approach taken to derive this model. Many research-grade projects, such as the eROV and the spherical AUV by Zavari et al. [30], develop a

comprehensive 6-DOF dynamic model from first principles. This process involves using CAD software to determine rigid-body parameters (mass, inertia) and Computational Fluid Dynamics (CFD) simulations to estimate hydrodynamic coefficients (drag, added mass) [5, 11]. This model-based design

allows for extensive simulation and controller tuning before physical construction. An alternative, empirical approach is system identification, where experimental data from a physical prototype is used to derive a transfer function model. This was successfully demonstrated by Aras et al. [3] for

the UTERG-ROV2, providing an accurate model for depth control without complex theoretical analysis. The choice of modelling approach represents a trade-off between theoretical rigour and the practicalities of physical testing.

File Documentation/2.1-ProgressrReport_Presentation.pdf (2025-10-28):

# Development of a Small Scale ROV for Research Purposes

Joshua Hecke
n11585382

# Project Overview

Task Description:
This project involves designing, building, and programming a miniature autonomous underwater vehicle to serve as a demonstrator for educational outreach and testing platform for underwater robotics research. The objective of this project is to create a small-scale submersible capable of controlled diving, surfacing, and maneuvering in test tanks or demonstration pools.

The final demonstrator should include:
1. Perform pre-programmed
missions including data
collection.
2. Help Complement ongoing research with our BlueROV
ROV by providing a
cost-effective platform
3. Help guide algorithm
development, open day
demonstrations, and initial machine learning pipeline
testing.

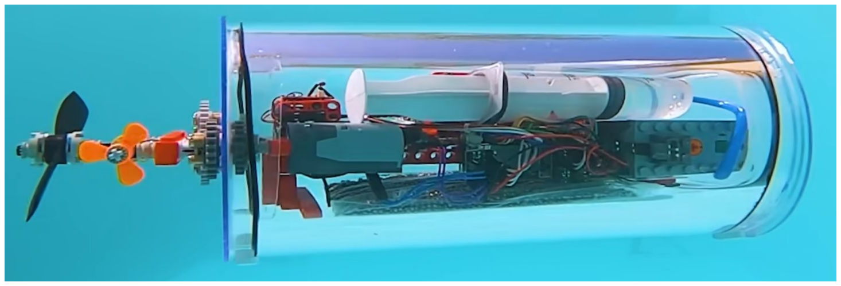
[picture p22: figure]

Photo of suggested approach by supervisor

# Project Breakdown

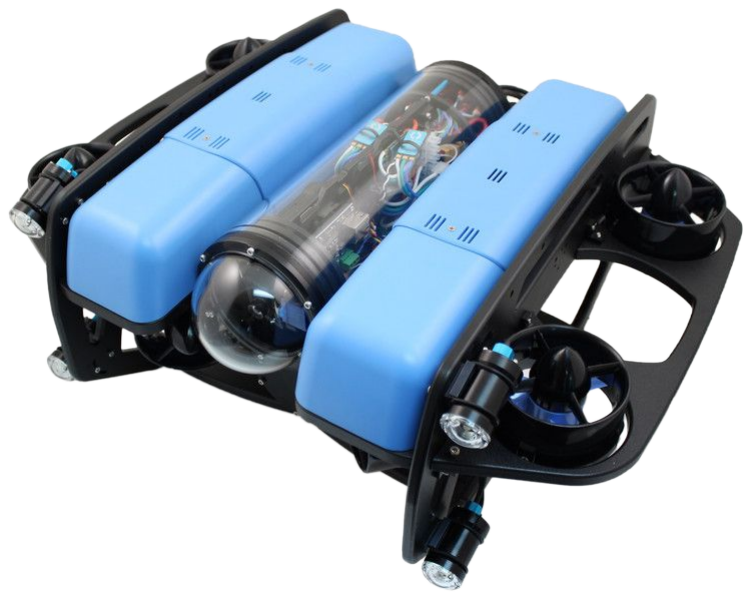
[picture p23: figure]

Research Topic: Development of a Small Scale ROV for Research Purposes

Research Question: How can a modular, small-scale ROV platform be developed using primarily Commercial Off-The-Shelf components to create a cost-effective and adaptable tool for undergraduate-level robotics education and system testing?

Research Problem: Currently the BlueROV2 ROV that QUT owns is too large and use requires additional steps including

- QUT pool approval and/or offsite setup
- Difficult manual handling
- This larger platform can be overkill for small tests

This project aims to design a smaller solution which directly

solves these problems | ?

# Literature Review

~60-70 papers were identified

ROV Focus: Based on components mentioned, likely references the BlueROV2 or similar, focusing on surveillance, inspection, and mapping.

Design Philosophy: Emphasizes modularity, stabilized frame, ease of operation, and high maneuverability with 5 Degrees of Freedom (DOF) using vectored thrusters.

Key Technologies:
Controller: Raspberry Pi with Pixhawk running ArduSub.
Structure: Open-frame structure; polyurethane foam for buoyancy. Propulsion: Six thrusters (4 vectored horizontal, 2 vertical) with integrated ESCs.
Sensors: Cameras, depth, temperature, pressure sensors. Suggests future addition of SONAR.
Communication: Tether with Fathom-X interface boards (Ethernet). Power: Lithium-polymer battery pack.

Relevance to Small Scale: The modular hardware (Pi, Pixhawk) and open-source software stack is directly applicable and scalable to smaller designs. The 6-thruster vectored configuration is effective for maneuverability in smaller frames.

# Modular Observation ROV(BlueROV2)

Photo of the rov used in
the paper

Jothikrishna et al. (2023)

# ArduinoSub: Leveraging Low-Cost Components for Education

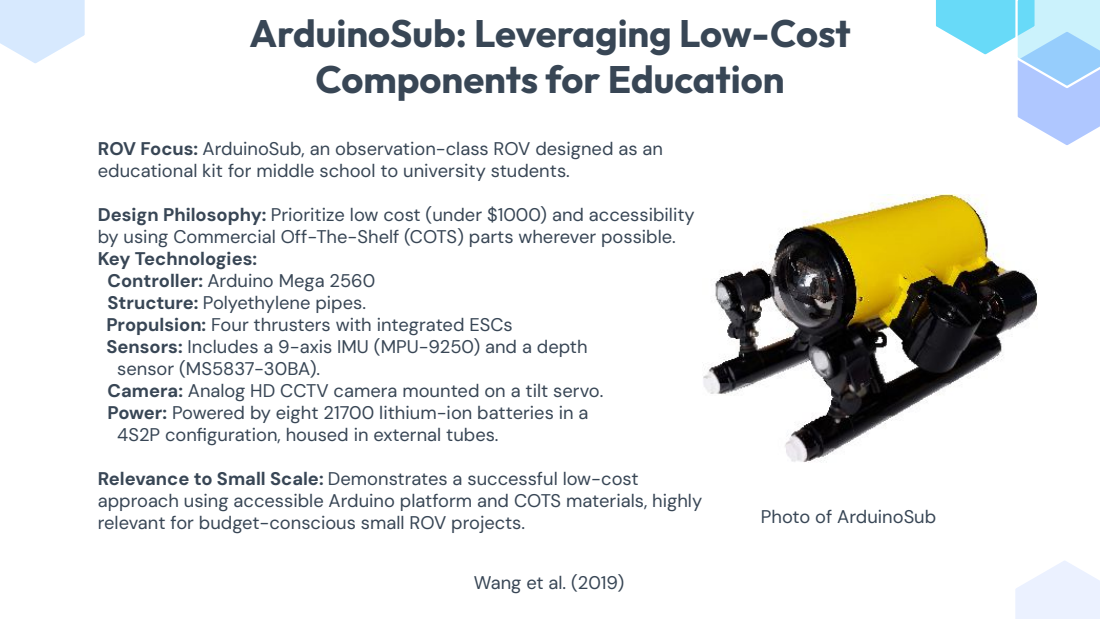
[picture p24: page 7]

ROV Focus: ArduinoSub, an observation-class ROV designed as an
educational kit for middle school to university students.

Design Philosophy: Prioritize low cost (under $1000) and accessibility
by using Commercial Off-The-Shelf (COTS) parts wherever possible.
Key Technologies:
Controller: Arduino Mega 2560
Structure: Polyethylene pipes.
Propulsion: Four thrusters with integrated ESCs
Sensors: Includes a 9-axis IMU (MPU-9250) and a depth
sensor (MS5837-30BA).
Camera: Analog HD CCTV camera mounted on a tilt servo.
Power: Powered by eight 21700 lithium-ion batteries in a
4S2P configuration, housed in external tubes.

Relevance to Small Scale: Demonstrates a successful low-cost
approach using accessible Arduino platform and COTS materials, highly
relevant for budget-conscious small ROV projects.

Photo of ArduinoSub

Wang et al. (2019)

# Hybrid ROV - Capstone Project

Photo of the rov designed
in the paper

Hur, B., & Alvi, M. (2022)

ROV Focus: Small-scale educational Hybrid ROV for shallow channel survey/exploration and MATE competitions. Operates tethered (manual) and tetherless (autonomous).

Design Philosophy: Educational platform for underwater robotics, enabling dual ROV/AUV modes and sensor data collection, including autonomous depth profiling.

Key Technologies:
Controller: Raspberry Pi Zero W (ROV), Raspberry Pi 3 B+ (Base Station).
Structure: Aluminum extrusion frame, waterproof enclosure. Propulsion: Six thrusters with ESCs and 16-Channel PWM/Servo Driver. Sensors: IMU, GPS, Pressure, Sonar, Water temperature.
Camera: 2.1 MP HD-SDI Camera, two LED lights.
Power: 12V Battery pack; tether-powered option.
Communication: Detachable tether, WiFi (surfaced).

Relevance to Small Scale: Robust, modular aluminum frame for prototyping. Hybrid tethered/tetherless design demonstrates small platform flexibility. Uses accessible components (Raspberry Pi, standard sensors).

ROV Focus: Kalypso, a hybrid Autonomous Underwater Vehicle (AUV) and Remotely Operated Vehicle (ROV) designed for aquaculture inspection and intervention in the Mediterranean.

Design Philosophy: Enhance aquaculture management via dual modes: AUV for autonomous net inspection and ROV for teleoperated intervention. Prioritizes cost-effectiveness through 3D printing.

Key Technologies:
Controller: Pixhawk board, Raspberry Pi 3, Mini PC.
Structure: 3D printed main body, acrylic tube WTE
Propulsion: Eight thrusters providing 6 Degrees of Freedom (DOF). Sensors: Leak sensors, underwater ultrasonic sensors, twin cameras IMU, compass, distance sensors
Power: Two 14.8V, 10,000 mAh LiPo batteries.
Software: Custom navigation algorithms and vision-based hole detection procedures.

Relevance to Small Scale: 3D printing provides adaptable, cost-effective construction for custom small-scale ROVs. The multi-board control architecture, distributing tasks across processors, is scalable to smaller platforms.

# Hybrid AUV/ROV for Aquaculture

Photo of the rov design

Manos et al. (2024)

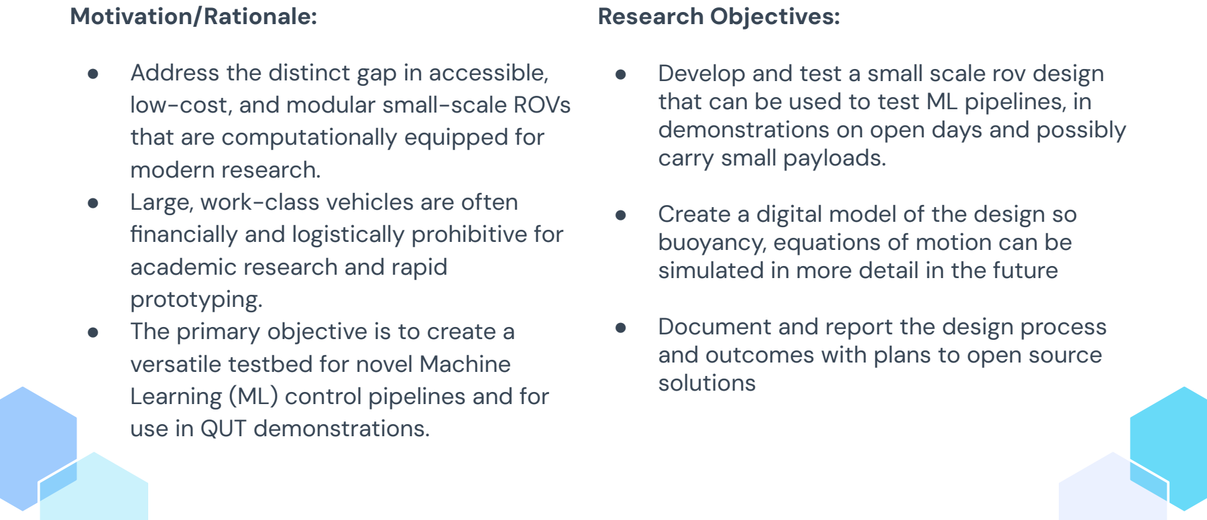
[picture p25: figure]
carry small payloads.; buoyancy, equations of motion can be simulated in more detail in the future; and outcomes with plans to open source solutions; low-cost, and modular small-scale ROVs that are computationally equipped for modern research. ● Large, work-class vehicles are often financially and logistically prohibitive for academic research and rapid prototyping. ● The primary objective is to create a versatile testbed for novel Machine Learning (ML) control pipelines and for use in QUT demonstrations.

- Develop and test a small scale rov design that can be used to test ML pipelines, in demonstrations on open days and possibly
- Create a digital model of the design so
- Document and report the design process
- Address the distinct gap in accessible,

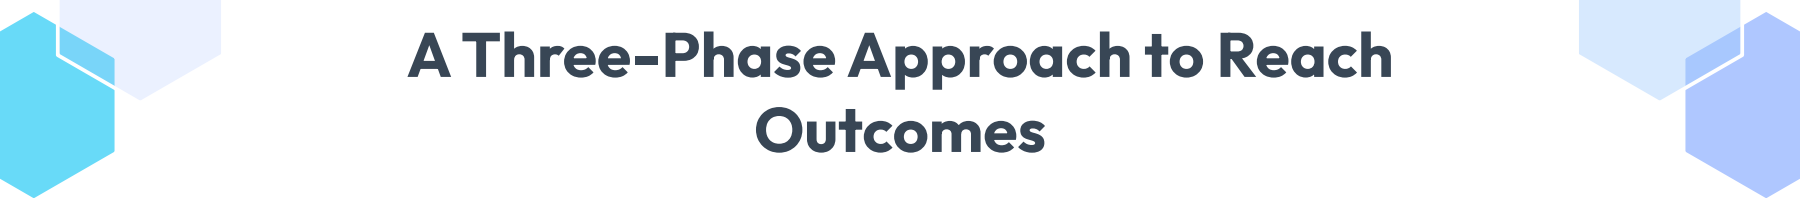
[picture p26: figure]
A Three-Phase Approach to Reach Outcomes

Phase 3: Reporting, Testing & Refinement
Testing: Conduct waterproof tests, Manual motion tests and possibly autonomous identification tests
Refinement: Use test results to refine a third stage solution that has evidence meeting research outcomes.
Reporting: Document all outcomes and finalize outcomes into a accessible package(Github repo)

Phase 1: Research and Design
Research: Research components and materials used in current solutions
Development: Iteratively design a first stage solution that meets research outcomes
Phase 2: Simulation and Prototyping
Simulation: Produce a digital twin that allows simulation of buoyancy and motion in ros2 using Solidworks documentation
Prototyping: Develop a second stage refined design based off simulation results

# Project Gantt Chart

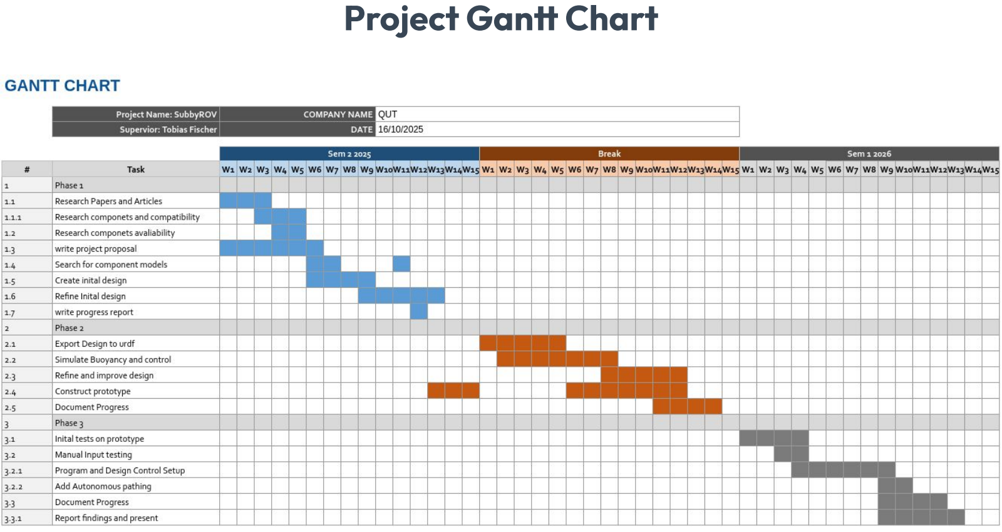
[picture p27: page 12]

# Project Progress

Phase 1

# Research

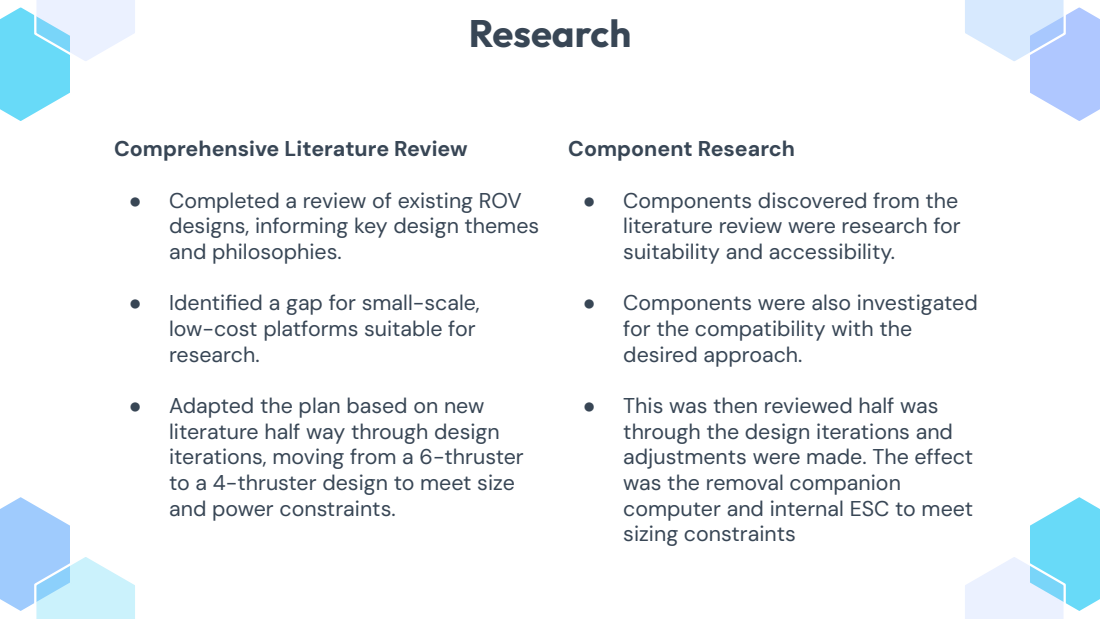
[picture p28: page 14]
Component Research

Comprehensive Literature Review

● Completed a review of existing ROV
designs, informing key design themes
and philosophies.

● Components discovered from the
literature review were research for
suitability and accessibility.

● Identified a gap for small-scale,
low-cost platforms suitable for
research.

● Components were also investigated
for the compatibility with the
desired approach.

● Adapted the plan based on new
literature half way through design
iterations, moving from a 6-thruster
to a 4-thruster design to meet size
and power constraints.

● This was then reviewed half was
through the design iterations and
adjustments were made. The effect
was the removal companion
computer and internal ESC to meet
sizing constraints

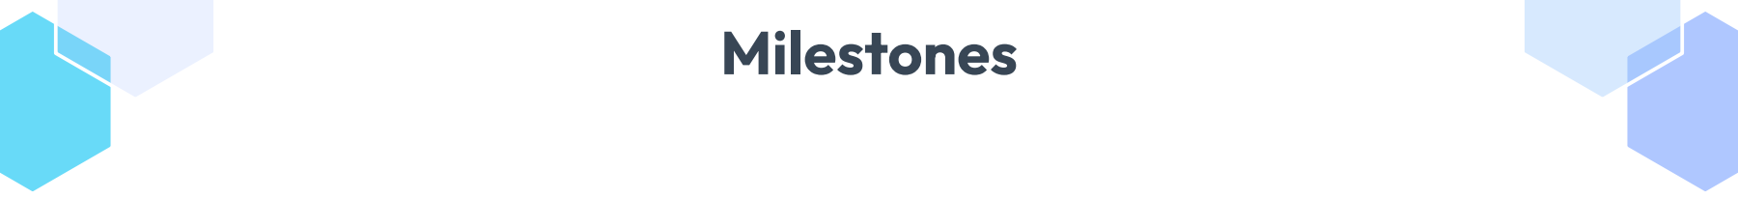
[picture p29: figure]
Milestones

Key Milestones Achieved

- Submitted a comprehensive Risk Assessment (ID: 18339) to the QUT HSE Hub.
- Completed multiple design iterations in SolidWorks 2023.
- Produced a detailed Bill of Materials (BOM)
- Began initial construction and assembly of the watertight enclosure (WTE) prototype.

# Risk Assessment

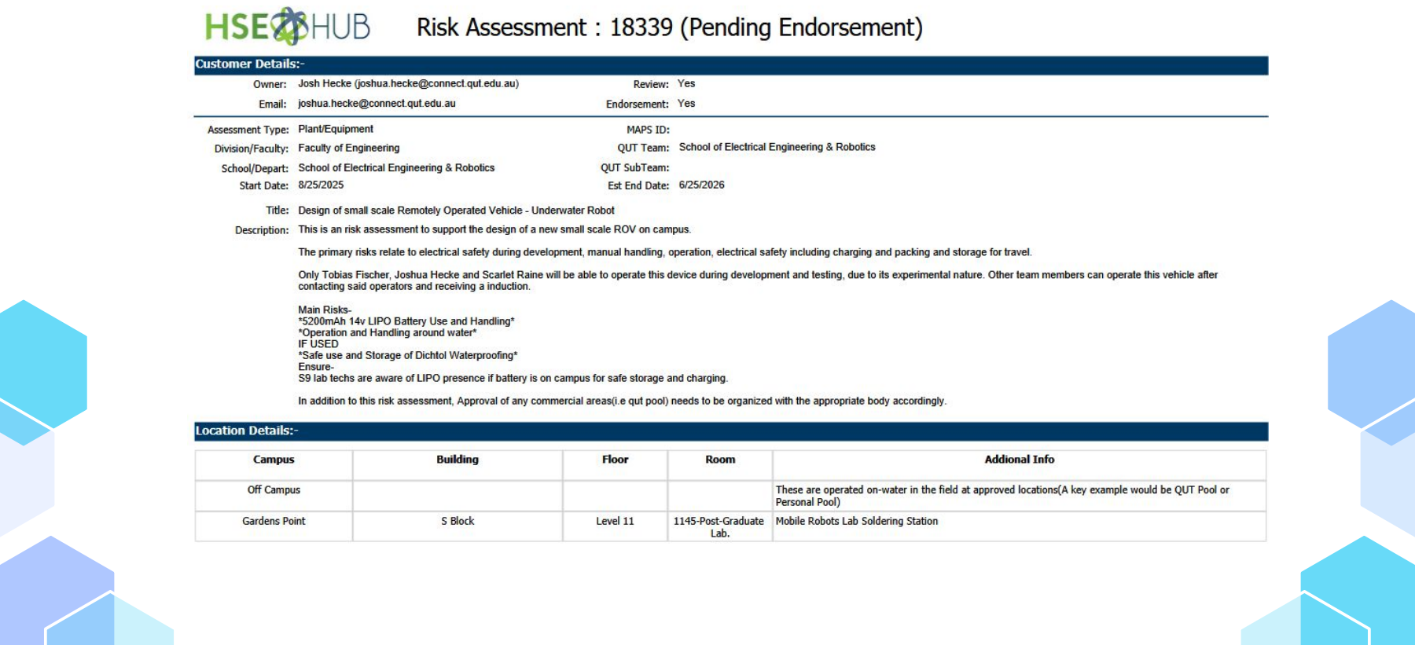
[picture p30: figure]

# Design Iterations #1

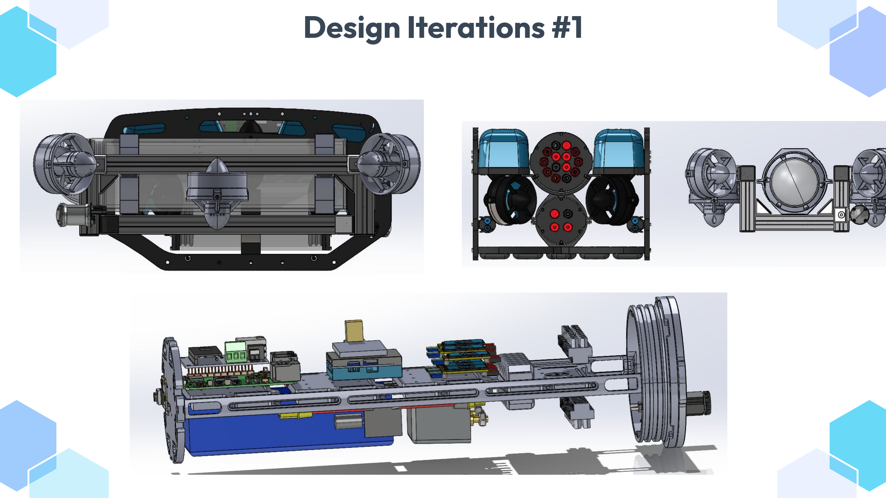
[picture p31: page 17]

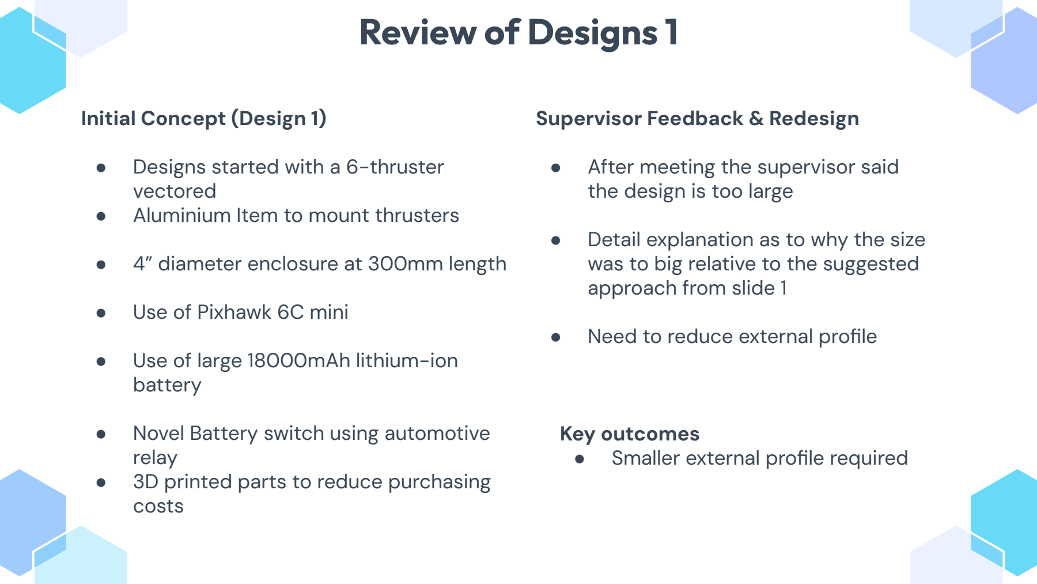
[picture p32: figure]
Review of Designs 1; Initial Concept (Design 1); ● Designs started with a 6-thruster vectored ● Aluminium Item to mount thrusters; ● 4” diameter enclosure at 300mm length; ● Use of Pixhawk 6C mini; ● Use of large 18000mAh lithium-ion battery; ● Novel Battery switch using automotive relay ● 3D printed parts to reduce purchasing costs; Supervisor Feedback & Redesign; ● After meeting the supervisor said the design is too large; ● Detail explanation as to why the size was to big relative to the suggested approach from slide 1; ● Need to reduce external profile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

Design Iterations #2

Review of Designs 2; Initial Concept (Design 2) ● Similar internal makeup however changes to the external profile made to reduce size; Supervisor Feedback & Redesign; ● Key changes: Reduce thrusters to 4, research smaller thrusters, remove companion computer and go straight to ground control, ESC outside of WTE, smarter 6X autopilot to replace companion computer; ● Due to the size reduction the Li-ion battery is now too large and a more energy dense LiPo battery is required.; Key outcomes ● Less components inside WTE ● Smaller battery for smaller thrusters

- A meeting resulted in a major design pivot.

# Design Iterations #3


Review of Designs 3; Initial Concept (Design 3); ● This design now uses a 5400mAh LiPo battery; 3" diameter watertight enclosure which reduces profile margin; bracket for the 4 thrusters to provide vectored force.; ● New camera as companion computer is now removed; external waterproof ESC; Core New Electronic Components; ● Main Controller: Pixhawk 6X flight controller.; ● Propulsion: 4x APISQUEEN U2 MINI thrusters with ESC.; ● Camera: Px4Flow; ● Power: Tattu 5200mAh 4S (14.8V) LiPo battery.; Key outcomes ● Px4Flow outdated ● Missing handling points

- The design is centered on a Blue Robotics
- It features an experimental 45-45 degree
- New thrusters with smaller profile and

# Design Iterations #4


# Design Iterations #4


Review of Designs 4; Final SolidWorks Model; ● New camera mount as design 3’s camera was unsourceable; ● Smaller relay as battery demand has decreased; ● New handle for easier Handling; ● Camera: Z-1 Mini gimballed camera.; Next Steps for the Design; ● Validate the designs buoyancy through simulation and add additional volume according to simulations; ● Investigate wire connections inside WTE; ● Design Ground station connection; ● Investigate Experimental 45-45 mount; ● Prototype to validate custom 3D printed mounting solutions

Bill of Materials (BOM) & Procurement; ● A full BOM has been produced.; is currently at ~$3000.; received, including the flight controller, thrusters, and enclosure components.; sensor is on reorder.; Initial Prototype Assembly; ● To validate the SolidWorks design, the initial construction of the WTE has started.; ● The internal electronics tray has been assembled, mounting the Pixhawk 6X, PDB-XT60, and Fathom-X boards.; ● This test-fitting confirmed the components fit well, with only minor modifications needed for mounting holes.

# Procurement & Initial Prototyping Status

- Total estimated cost for all components
- All critical long-lead items have been
- Mounting hardware is on order; the power

# Condensed BOM


# Project Outcomes and Broader Impact

Expected Outcomes:; 1. A fully assembled and operational small-scale underwater ROV.; 2. Complete Computer-Aided Design (CAD) drawings and a detailed Bill of Materials (BOM) for the final design.; 3. Control system software with a camera view.; 4. A final report detailing the design methodology, validation, and performance results.; Benefits & Impact:; low-cost testbed for QUT demonstrations and future student projects, enabling hands-on learning in marine robotics, control systems, and sensor integration.; (ML) control pipelines, serving as a foundation for more advanced research.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

- Academic & Research: Creates a versatile,
- Future Innovation: Provides an adaptable platform for testing novel Machine Learning

modular and repairable design using COTS

Conclusion and Future Directions; Phase 1 complete: ● literature review, CAD mechanical design, and component procurement are finalized.; ● The 4-thruster vectored configuration is optimized for size and power, with a 30-minute theoretical runtime confirmed by power budget analysis.; ● With most components on hand, the project transitions from theoretical design to physical assembly and integration.; Future Work: The start of Phase 2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

# References

Hur, B., & Alvi, M. (2022). Educational Small Scale Underwater Robot Development via a Capstone Project in Engineering Technology. ASEE Annual Conference and Exposition, Conference Proceedings.

Jothikrishna, K., Rithika, S. M., Swetha, S. V., & Kavitha, K. (2023). Remotely Operated Underwater Vehicle (ROV). 2023 2nd International Conference on Advancements in Electrical, Electronics, Communication, Computing and Automation (ICAECA), 1–4. https://doi.org/10.1109/ICAECA56562.2023.10200265

Manos, N., Kavallieratou, E., & Vasilopoulos, N. (2024). Kalypso: An inspection AUV for aquaculture. Probe - Fishery Science & Aquaculture, 6(1), 2239. https://doi.org/10.18686/fsa2239

Sabri, W. M. A. B. W., Zabidi, I. R., Musthalib, M. A. M. A., Muhamad, Z. A., Hazman, M. I. M., Yusof, M. S. M., Naing, L., & Abidin, Z. Z. (2017). Low-cost remotely operated underwater vehicle for underwater observation purposes. 2017 IEEE 7th International Conference on Underwater System Technology: Theory and Applications (USYS), 1–5. https://doi.org/10.1109/USYS.2017.8309444

Wang, W., Pang, S., Wu, T., & Han, B. (2019). ArduinoSub—A Low-Cost ROV Kit for Ocean Engineering Education. OCEANS 2019 MTS/IEEE SEATTLE, 1–6. https://doi.org/10.23919/OCEANS40490.2019.8962404

# Any Questions?

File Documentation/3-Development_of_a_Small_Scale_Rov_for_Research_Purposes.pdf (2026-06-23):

# Development of a Small-Scale Underwater Remotely Operated Vehicle (ROV)

Unit Code: | EGH490-2 - Research Project 2
Assessment: | #1 - Final Project Delivery Report
Supervisor: | Tobias Fischer
Mechatronics Engineer: | Joshua Hecke¹
Student ID: | n11585382
Simulation Engineer: | Brad Edwards²
Student ID: | n11585382

This report is submitted in partial fulfilment of the requirements for EGH490-2.

1

CONTENTS

I | Introduction | 1
I-A | Context & Motivation: | | 1
I-B | Problem Statement: | | 1
I-C | Objectives & Scope: | | 2
I-D | Team Dynamics: | | 2
II | Literature Review | 2
II-A | Literature Review Summary | | 2
II-B | Evaluation of Literature Review Findings and New Literature | | 3
III | Methodology & System Design | 4
III-A | Design Goals and Iterative Design Process | | 4
III-B | Software and Hardware Selection | | 5
III-B1 | Design and Simulation | | 5
III-B2 | Control Software | | 5
III-C | Material Selection | | 5
III-D | Electronic System Selection and Design | | 6
III-D1 | Payload | | 6
III-D2 | Power Distribution and Safety Control Loop | | 6
III-D3 | Flight Control and Propulsion | | 6
III-D4 | Payload and Video Integration | | 6
III-D5 | Communication Architecture | | 7
III-D6 | System Architecture | | 7
IV | Implementation & Prototyping | 7
IV-A | Design Phase | | 7
IV-B | Production Phase | | 7
IV-B1 | Development Roadblocks | | 7
IV-B2 | Buoyancy and Stability Design | | 9
IV-C | Design Specification | | 11
V | Testing & Results | 11
V-1 | Thruster, Payload and Kill Switch Testing | | 11
V-2 | Simulation Testing | | 12
V-3 | Physical Testing | | 14
V-4 | Testing Comparison | | 15
VI | Discussion and Project Evaluation | 16
VI-1 | Safety and Risks | | 16
VI-2 | Environmental Impact | | 16
VI-3 | Limitations and Weaknesses | | 16
VI-4 | Goals and Objectives | | 18
VII | Conclusion | 18
References | 19
VIII Appendices | 20
VIII-A Appendix A: Original Literature Review (from Project Proposal) | | 20
VIII-A1 | Introduction | | 20
VIII-A2 | Methodology and Scope | | 21
VIII-A3 | Key Design Themes | | 21
VIII-A4 | Hardware Selections | | 22
VIII-A5 | Software and Communication Frameworks | | 22
VIII-A6 | Control System Architectures | | 23
VIII-A7 | System Modelling Approaches | | 23
VIII-B Appendix B: Comprehensive Bill of Materials (BOM) & Full Budget | | 23
VIII-C Appendix C: Project Timelines | | 25
VIII-D Appendix D: CAD Models | | 27
VIII-E | Appendix E: Risk Assessment | | 29

1
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

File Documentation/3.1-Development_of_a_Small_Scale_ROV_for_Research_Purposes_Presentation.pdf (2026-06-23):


# Development of a Small Scale ROV for Research Purposes

## Joshua Hecke

n11585382

## under tutelage of

## Tobias Fischer


# Project Overview

### Task Description:

This project involves designing, building, and programming a miniature autonomous underwater vehicle to serve as a
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

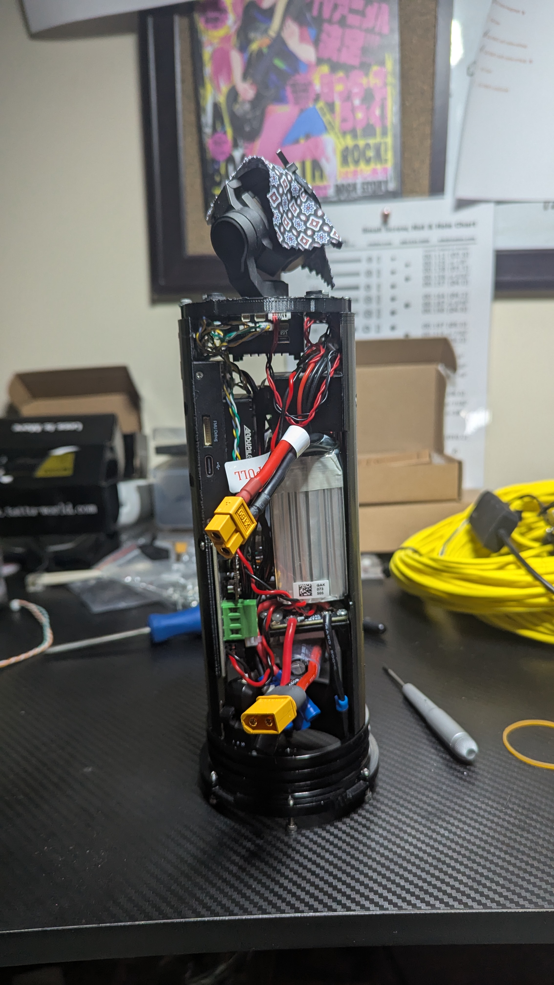
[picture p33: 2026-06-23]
Showcase/Development/v3_internal_real.jpg

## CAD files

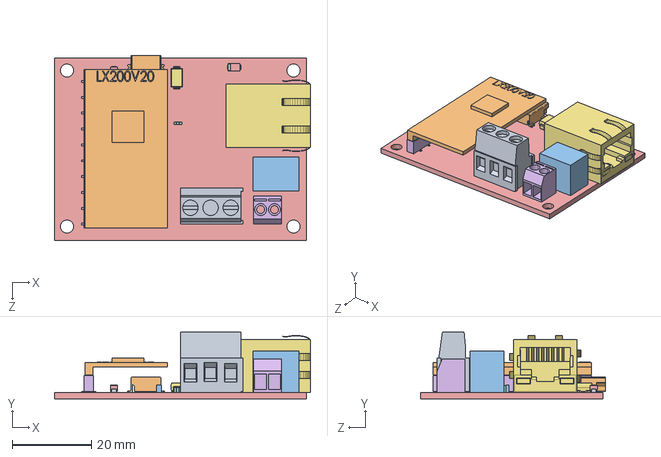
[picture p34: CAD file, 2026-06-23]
CAD/STEPFiles/parts/FATHOM-X-ASM-R1.STEP
64.6 x 16.8 x 46.6 mm

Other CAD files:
StonefishSimulation/cad_model_data/rov_model_files/stl_files/Full_Assembly_minusfoamies.STL
CAD/STEPFiles/parts/Camera_assembly.STEP
CAD/STEPFiles/parts/LUMEN-ASM-R3-PUBLIC.STEP.STEP
CAD/STEPFiles/parts/Hull_v5.STEP
StonefishSimulation/cad_model_data/cw_smaller082.obj
StonefishSimulation/cad_model_data/ocean_test_data/anode.obj
StonefishSimulation/cad_model_data/rov_model_files/obj_versions_parts/Inside_hull.obj
StonefishSimulation/cad_model_data/rov_model_files/stl_files/foamfloaties.STL
StonefishSimulation/cad_model_data/rov_models/2k_updated_Subbyrov.obj
CAD/STEPFiles/parts/D5.step.STEP
StonefishSimulation/cad_model_data/ccw_f.obj
StonefishSimulation/cad_model_data/ocean_test_data/gas_canister.obj
StonefishSimulation/cad_model_data/rov_model_files/obj_versions_parts/Buoyancy_handle.obj
StonefishSimulation/cad_model_data/rov_model_files/stl_files/camera.STL
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

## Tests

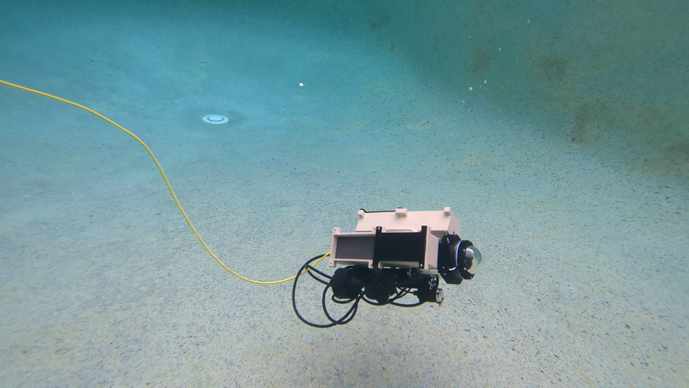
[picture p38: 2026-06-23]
Showcase/Development/test2_image2.png

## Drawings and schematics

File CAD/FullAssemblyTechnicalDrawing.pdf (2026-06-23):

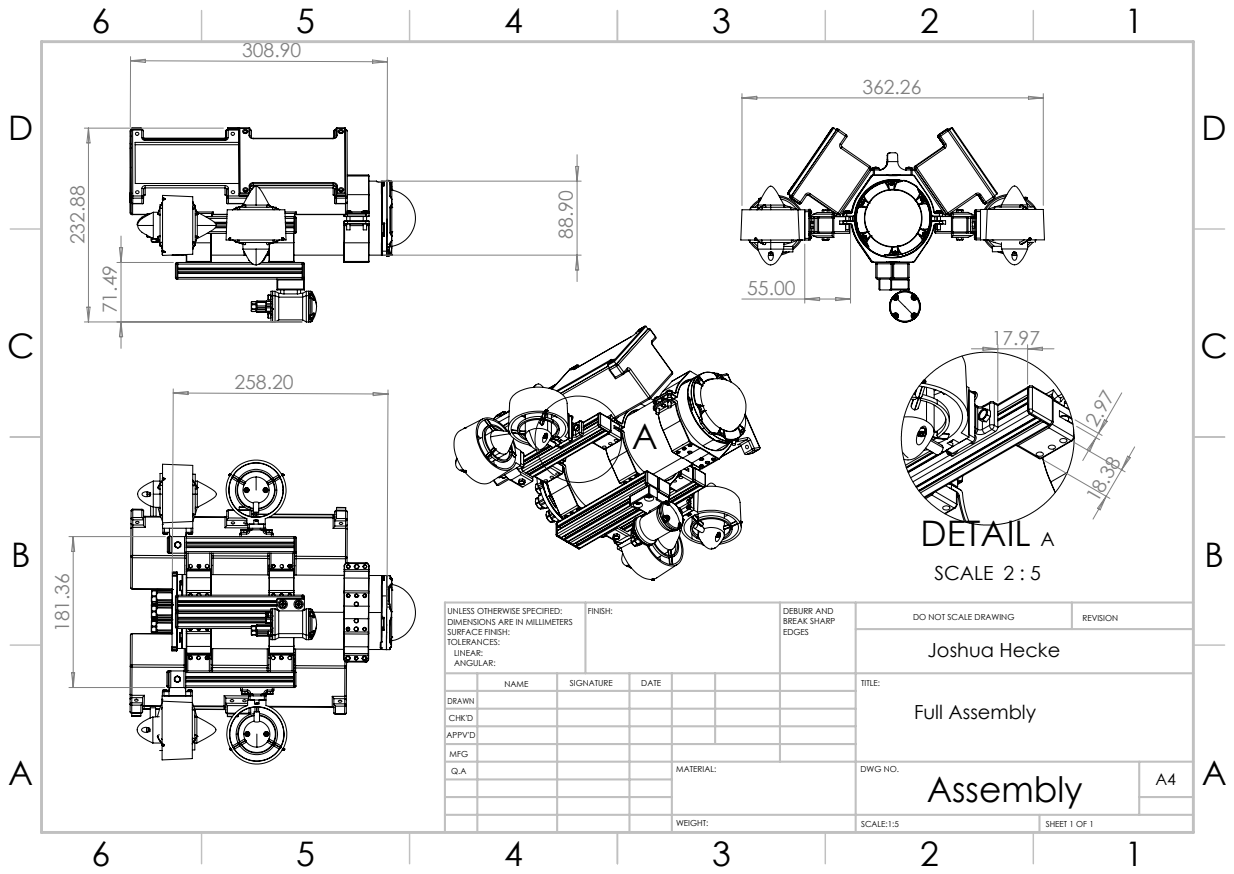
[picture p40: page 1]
SCALE 2 : 5; Joshua Hecke; FINISH:; DEBURR AND; BREAK SHARP; DO NOT SCALE DRAWING; REVISION; SCALE:1:5; SHEET 1 OF 1

UNLESS OTHERWISE SPECIFIED:
DIMENSIONS ARE IN MILLIMETERS
SURFACE FINISH:
TOLERANCES:
LINEAR:
ANGULAR:

NAME | SIGNATURE | DATE | | | | TITLE: Full Assembly

DRAWN
CHK'D
APPV'D
MFG
Q.A | | | | MATERIAL: | DWG NO. Assembly | A4

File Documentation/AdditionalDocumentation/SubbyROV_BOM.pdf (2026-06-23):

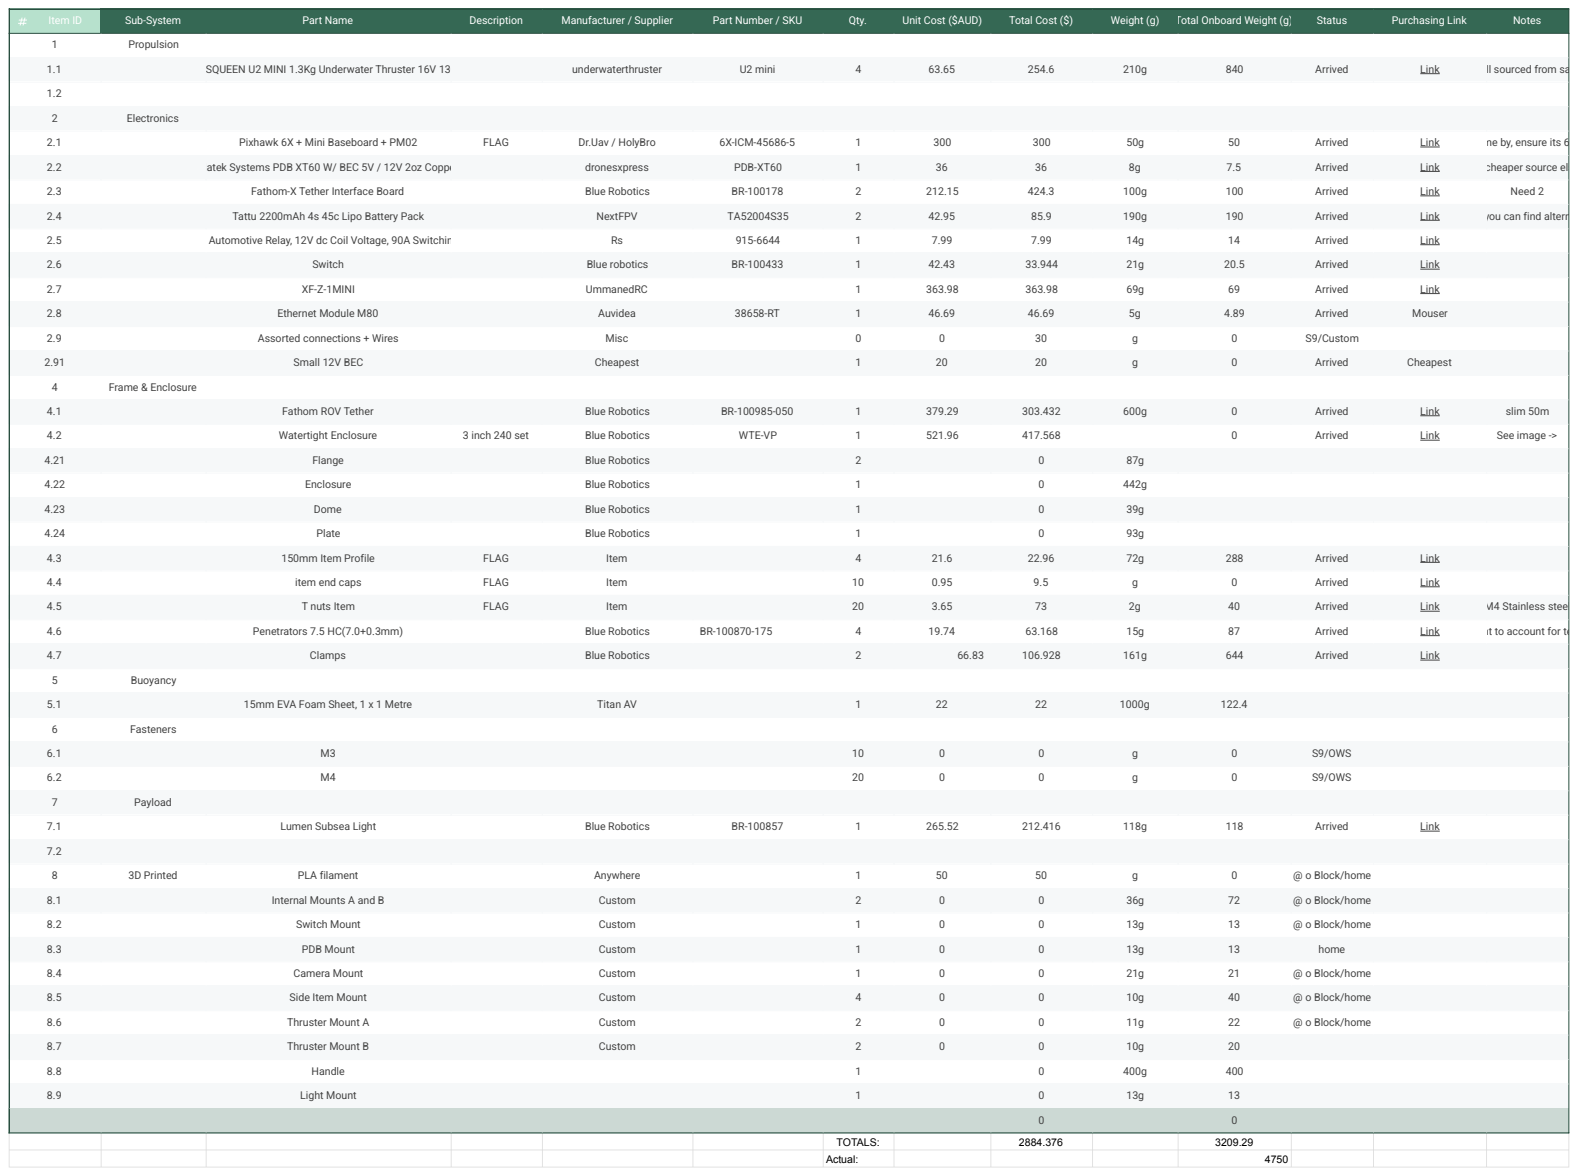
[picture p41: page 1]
Item ID; Sub-System; Part Name; Description; Manufacturer / Supplier; Part Number / SKU; Qty.; Unit Cost ($AUD); Total Cost ($); Weight (g); Total Onboard Weight (g); Status; Purchasing Link; Notes; Propulsion; APISQUEEN U2 MINI 1.3Kg Underwater Thruster 16V 130W; underwaterthruster; U2 mini; Arrived; Link; Electronics; Pixhawk 6X + Mini Baseboard + PM02; FLAG; Dr.Uav / HolyBro; 6X-ICM-45686-5; Matek Systems PDB XT60 W/ BEC 5V / 12V 2oz Copper; dronesxpress; PDB-XT60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

TOTALS: | 2884.376 | 3209.29
Actual: | | 4750

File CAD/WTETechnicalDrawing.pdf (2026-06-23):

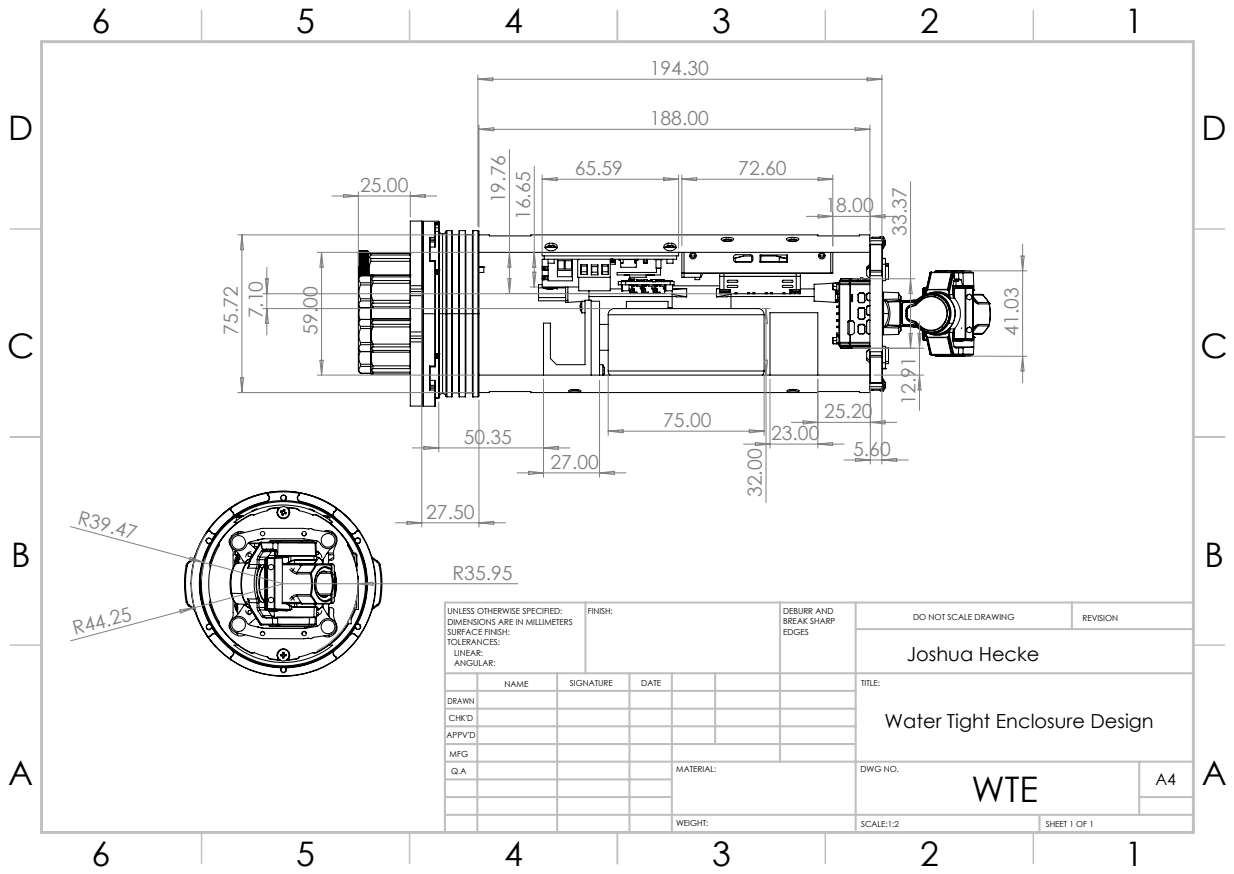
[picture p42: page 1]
Joshua Hecke; FINISH:; DEBURR AND; BREAK SHARP; DO NOT SCALE DRAWING; REVISION; SCALE:1:2; SHEET 1 OF 1

UNLESS OTHERWISE SPECIFIED:
DIMENSIONS ARE IN MILLIMETERS
SURFACE FINISH:
TOLERANCES:
LINEAR:
ANGULAR:

NAME | SIGNATURE | DATE | | | | TITLE: Water Tight Enclosure Design

DRAWN
CHK'D
APPV'D
MFG
Q.A | | | | MATERIAL: | DWG NO. WTE | A4

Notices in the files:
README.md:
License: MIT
